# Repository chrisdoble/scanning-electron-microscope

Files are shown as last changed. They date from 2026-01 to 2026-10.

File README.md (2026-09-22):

This repository contains my DIY scanning electron microscope project.

My initial goal is to image samples using secondary electron emission and control the microscope from my computer.

I'm also documenting the process on YouTube [here](https://www.youtube.com/playlist?list=PLmlXFuUXRl5AR0MqcsTuL44zxy5YJyGKN).

# Roadmap

- [x] Purchase vacuum equipment
  - Edwards ADC MkII gauge controller
  - Edwards WRG-S wide range pressure gauge
  - Pfeiffer TC-600 turbomolecular pump controller
  - Pfeiffer TMH 071 P turbomolecular pump
- [x] Build a controller for the vacuum equipment
- [ ] Build a filament characterisation system
- [ ] Build an electron gun
- [ ] Build electrostatic or electromagnetic lenses
- [ ] Build an Everhart-Thornley detector
- [ ] ???
- [ ] Look at stuff

# Repository structure

The repository structure is as follows:

- [`controller`](controller): Contains files relating to the controller hardware that enables communication with the vacuum equipment, controls relays, etc.
- [`common`](common): A Rust crate containing code common to `firmware` and `host`.
- [`electron-gun-simulation`](electron-gun-simulation): A web-based simulation of an electron gun.
- [`filament-characterisation`](filament-characterisation): Contains files relating to the hardware and software used to characterise tungsten filaments to be used in the SEM.
- [`host`](host): A Rust crate containing both a library for interfacing with the controller hardware (pressure gauge, turbo molecular pump, etc.) and a binary for doing the same via a TUI.
- [`usb-tmc`](usb-tmc): A Rust crate containing an implementation of the [USB Test and Measurement Class](https://www.usb.org/document-library/test-measurement-class-specification) for interfacing with oscilloscopes, power supplies, etc.

# Required hardware

- A [Rigol DHO-814 oscilloscope](https://core-electronics.com.au/rigol-dho-814-oscilloscope.html)
- A [Rigol DP-932E power supply](https://core-electronics.com.au/rigol-dp-932e-triple-output-dc-power-supply.html)
- The custom controller as detailed in the [`controller`](controller) directory.
- The vacuum equipment mentioned above

# Running

See each directory's `README.md` for instructions.

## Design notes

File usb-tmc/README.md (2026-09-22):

A small async Rust library for communicating with a single USBTMC (USB Test
and Measurement Class) instrument — e.g. an oscilloscope or power supply —
over its bulk endpoints, built on [`rusb`].

See [`docs/API.md`](docs/API.md) for the full API design.

[`rusb`]: https://docs.rs/rusb

# Requirements

- [Rust](https://rust-lang.org/)
- [libusb](https://libusb.info/), e.g. via `brew install libusb` on macOS

# Features

- Find a device by USB vendor/product ID, open it, and locate its USBTMC
  interface and bulk endpoints.
- Read the interface's capabilities (`GET_CAPABILITIES`) and, if it accepts
  them, assert REN (`REN_CONTROL`), without which a USB488 instrument may
  ignore everything it's sent until something else takes it out of local mode.
- Send a message to the device (`DEV_DEP_MSG_OUT`).
- Request a response and read it back in full
  (`REQUEST_DEV_DEP_MSG_IN`/`DEV_DEP_MSG_IN`), reassembling multi-transfer
  responses using the End-Of-Message (EOM) bit.

# Limitations

- No support for the control-endpoint requests used to abort or recover a
  stuck transfer — if the host and device get out of sync, drop and reopen
  the `UsbTmcDevice`. Note that reopening asserts REN again but doesn't clear
  the device's bulk pipes, which is what `INITIATE_CLEAR` is for.
- REN is asserted on every `open` and never released — there's no
  `GO_TO_LOCAL`, so an instrument stays in remote mode until its Local key is
  pressed or it's power cycled.
- `read` relies solely on the EOM bit; `TermChar`-based early termination
  isn't supported.
- If multiple devices match the given vendor/product ID, `open` returns an
  error rather than picking one.
- Targets macOS — `open` doesn't attempt to detach a kernel driver before
  claiming the interface.

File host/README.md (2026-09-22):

This crate contains both a library for interfacing with the controller hardware (pressure gauge, turbo molecular pump, etc.) and a binary for doing the same via a TUI.

# Requirements

- [libusb](https://libusb.info/), e.g. via `brew install libusb` on macOS
- [Rust](https://rust-lang.org/)

# Running

1. Run `cargo run --bin vacuum -- <device path> <ADC gauge number> <TMP address>`, e.g. `cargo run --bin vacuum -- /dev/tty.usbmodem11201 1 001`.

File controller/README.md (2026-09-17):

This directory contains files relating to the controller hardware that enables communication with the vacuum equipment, controls relays, etc.

# Directory structure

- [`case`](case): 3D models of the controller case for 3D printing.
- [`electronics`](electronics): KiCad files for the controller PCB.
- [`firmware`](firmware): A Rust crate containing the [Embassy](https://github.com/embassy-rs/embassy)-based firmware for the controller.

# Required hardware

- The PCB detailed in the KiCad files including
  - [Raspberry Pi Debug Probe](https://www.raspberrypi.com/documentation/microcontrollers/debug-probe.html)
  - [Raspberry Pi Pico 2](https://www.raspberrypi.com/products/raspberry-pi-pico-2/)
  - [UART-to-RS-232 converter](https://core-electronics.com.au/rs232-to-serial-converter.html)
  - [UART-to-RS-485 converter](https://core-electronics.com.au/ttl-uart-to-rs485-converter-module.html)
  - Various headers and resistors
- 2 x [SPDT relays](https://core-electronics.com.au/gravity-digital-relay-module-arduino-and-raspberry-pi-compatible.html) for reversing filament heating current
- 6 x [Banana sockets](https://www.jaycar.com.au/red-deluxe-binding-post/p/PT0453)

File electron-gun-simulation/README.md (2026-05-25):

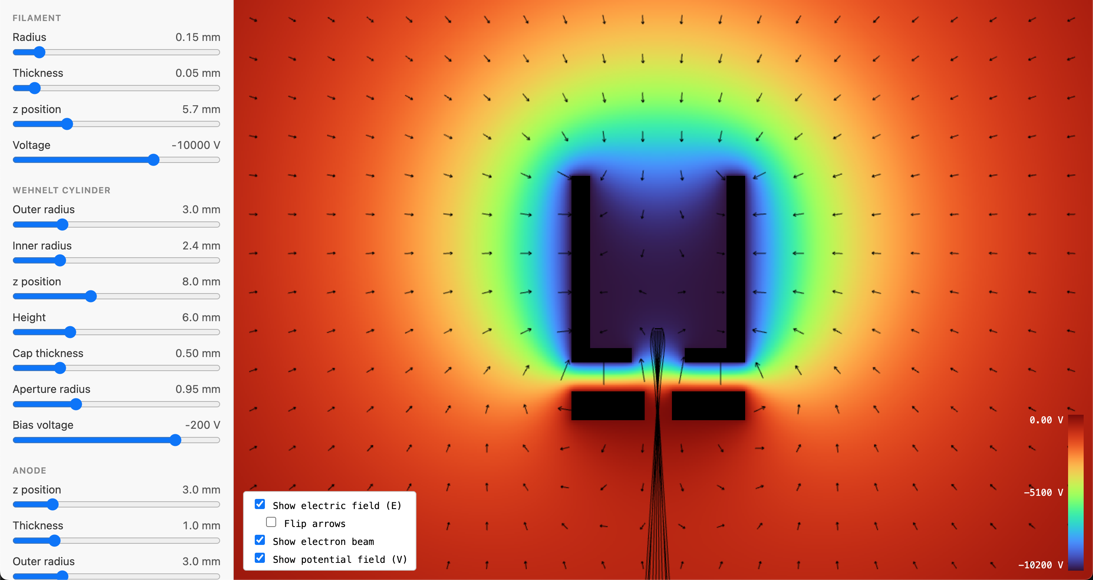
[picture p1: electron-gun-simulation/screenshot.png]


# Requirements

- [pnpm](https://pnpm.io/)
- [Rust](https://rust-lang.org/)
- [wasm-pack](https://wasm-bindgen.github.io/wasm-pack/)

# Running

1. Run

   ```console
   $ (cd crates/wasm-api && wasm-pack build -t web)
   $ cd web
   $ pnpm install
   $ pnpm dev
   ```

1. Open the URL printed in your terminal.

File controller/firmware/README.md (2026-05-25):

# Requirements

- [probe-rs](https://probe.rs/)
- [Rust](https://rust-lang.org/)

# Running

1. Connect the Pi Debug Probe and Pico 2 to your computer.
1. Run `cargo run`. This uploads the firmware to the Pico 2 via the Debug Probe, runs it, and prints subsequent log messages. You don't need to run this again unless you change the firmware or want to see log messages.

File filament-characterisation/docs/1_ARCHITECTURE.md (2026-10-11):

# Filament Characterisation TUI — Specification

A Ratatui application that drives the DIY SEM vacuum rig and steps an operator
through characterising a tungsten filament.

This document specifies **structure only**. The actual characterisation physics
and measurement logic are deliberately stubbed — the deliverable is a skeleton
that compiles, runs against mock hardware, renders the UI, executes a
step-by-step procedure, handles user input, records measurements to a
serialisable struct, shells out to Python for statistics, and cleans up safely
on error.

---

## 1. Goals

1. Reuse the existing `Adc`, `Tmp` and `Controller` types, and the forthcoming
   `PowerSupply` and `Oscilloscope` types, from the `host` crate.
2. Separate concerns into Tokio tasks: hardware polling, procedure execution,
   terminal input, rendering.
3. Model the procedure as a tree of **steps** written as ordinary sequential
   code, rendered as a scrollable, nested list.
4. Support user interaction mid-procedure (confirmations, value entry).
5. Collect measurements — raw samples and the values derived from them — into a
   single in-memory struct written to disk at explicit checkpoints, so a run
   that fails part-way still leaves usable data behind.
6. Run without hardware attached (`--mock`) so the UI can be compiled and
   exercised away from the rig.
7. Delegate statistics and uncertainty propagation to Python scripts shipped
   inside the crate, run through a virtual environment verified at start-up.
8. Guarantee that any error, panic or quit runs a cleanup routine that puts the
   filament system into a safe state.

## 2. Non-goals

- No real characterisation logic. Procedure steps perform sleeps, mock reads
  and placeholder measurements.
- **No emission-current measurement.** That comes in a later version; §17 lists
  the extension points that must stay open for it.
- No charts. Every step renders as text; §9.4 explains what adding a chart later
  would cost.
- No statistics in Rust. The crate records samples and calls Python to turn them
  into a value and an uncertainty.
- No realistic hardware simulation. The mocks return canned values so the UI
  compiles and runs; they are not a model of the rig.
- No fleshing out of the measurement struct. It has almost no fields yet by
  design (§10).

## 3. Assumptions

Implement against these; flag them in the PR description rather than guessing
differently.

| # | Assumption |
|---|---|
| A1 | `filament-characterisation/` is a new **grouping directory**, a sibling of `host/` and `common/` in the existing Cargo workspace. It is not itself a crate. |
| A2 | The new crate lives at `filament-characterisation/characteriser/`, is named `characteriser`, and defines its binary in `src/main.rs`. Add it to the workspace `members`. |
| A3 | The filament power supply, its polarity relays and the four-terminal sense measurement are reached through `host::power_supply::PowerSupply` and `host::oscilloscope::Oscilloscope`. `PowerSupply` holds its own `Arc<Controller>`, through which it switches the SPDT relays. Both instruments are found by hard-coded USB vendor and product IDs — never by command line argument. |
| A4 | The vacuum hardware is reached exactly as the existing binary does: one `Controller` over serial, shared by `Adc` and `Tmp` via `Arc`. The same `Controller` is shared with `PowerSupply`. |
| A5 | Shared dependency versions are hoisted from `host` into `[workspace.dependencies]` and pinned there (§4.1). Take the versions `host` currently declares; do not upgrade anything as part of the move. |
| A6 | Keep `#[tokio::main(flavor = "current_thread")]` as in the existing binary. All blocking serial I/O already happens inside `spawn_blocking` within `Controller`. |
| A7 | `host` depends on `serde` only to derive `Serialize`/`Deserialize` on plain data types that the results store directly, such as `Polarity` (§7.2). This supersedes the original "`host` stays free of `serde`"; see `2_COLD_RESISTANCE.md`. |
| A8 | The Python virtual environment lives at `characteriser/python/.venv` and is created by the operator, not by the application (§12). |
| A9 | Development and operation are on macOS/Linux. Paths like `python/.venv/bin/python` are used directly, without a Windows branch. |

---

## 4. Workspace layout

```
filament-characterisation/
  characteriser/
    Cargo.toml
    python/
      .venv/                        // created by the operator with uv, gitignored
      .python-version               // the Python version the environment uses
      requirements.txt              // pins `jsonschema`, `numpy`, `scipy` and `uncertainties`
      schemas/                      // input and output schemas, generated from the Rust types
      script_io.py                  // reads and validates a script's input, writes its output
      mean_and_standard_error.py    // samples in, value and uncertainty out
      cold_resistance_point.py      // one setpoint's two polarities in, its resistance out
      cold_resistance_fit.py        // every setpoint in, R0 and its uncertainty budget out
      test_cold_resistance.py       // the scripts' tests, run with `python -m unittest`
    src/
      main.rs                 // args, logging, start-up checks, task wiring, error handling
      app.rs                  // App state, event loop, key handling
      hardware/
        mod.rs                // traits, snapshots, the Hardware bundle
        real.rs               // impls over Adc / Tmp / PowerSupply / Oscilloscope
        mock.rs               // canned-value implementations
      procedure/
        mod.rs                // Context and the procedure runner
        characterisation.rs   // the procedure itself
      python.rs               // venv verification and script invocation
      results.rs              // Characterisation, Measurement, serialisation
      steps.rs                // Step, Section, and their rendering
      ui/
        mod.rs                // layout + top-level render
        filament.rs           // filament stats block
        run.rs                // run status block
        steps.rs              // scrollable step list
        vacuum.rs             // vacuum stats block
```

Add `python/.venv/` and `out/` to `.gitignore` if they aren't there already.

### 4.1 Hoisting dependencies to the workspace

Before writing any application code, move the shared dependencies out of
`host/Cargo.toml` (and the existing binary's) into the workspace root:

```toml
# Cargo.toml (workspace root)
[workspace.dependencies]
clap = { version = "<as in host>", features = ["derive"] }
crossterm = "<as in host>"
env_logger = "<as in host>"
log = "<as in host>"
ratatui = "<as in host>"
serde = { version = "<as resolved>", features = ["derive"] }
serialport = "<as in host>"
thiserror = "<as in host>"
tokio = { version = "<as in host>", features = ["macros", "rt", "sync", "time"] }
```

Pin each to the exact version currently resolved in `Cargo.lock` so this move
changes nothing at build time. Then rewrite the member crates to use
`dependency = { workspace = true }`, adding extra features locally where needed.
Verify with `cargo tree` that no version changed, and that `host` and the
existing binary still build, before moving on.

The new crate's manifest:

```toml
[dependencies]
async-trait = "0.1"
clap = { workspace = true }
common = { path = "../../common" }
crossterm = { workspace = true, features = ["event-stream"] }
env_logger = { workspace = true }
futures = "0.3"              # StreamExt, for the crossterm EventStream
host = { path = "../../host" }
log = { workspace = true }
ratatui = { workspace = true }
serde = { workspace = true }
serde_json = "1"
thiserror = { workspace = true }
tokio = { workspace = true, features = ["process"] }
tokio-util = { version = "0.7", features = ["rt"] }   # CancellationToken
```

---

## 5. Command line arguments

Identical to the existing binary, plus `--mock`. Positional arguments become
optional only when `--mock` is given. **No arguments are added for the power
supply, the oscilloscope or the Python environment** — those are located by
hard-coded constants.

```rust
#[derive(Parser)]
struct Arguments {
    /// The path to the controller device, e.g. /dev/tty.usbmodem11201.
    #[arg(required_unless_present = "mock")]
    device_path: Option<String>,

    /// The gauge number to use when communicating with the ADC, e.g. 1.
    #[arg(
        required_unless_present = "mock",
        value_parser = clap::value_parser!(u8).range(1..=2)
    )]
    adc_gauge_number: Option<u8>,

    /// The address of the TMP in the RS-485 Pfeiffer Vacuum Protocol, e.g. 001.
    ///
    /// This corresponds to TMP parameter 797.
    #[arg(required_unless_present = "mock")]
    tmp_address: Option<String>,

    /// Run against simulated hardware instead of the real rig.
    #[arg(long)]
    mock: bool,
}
```

---

## 6. Logging

Copy `init_logging` from the existing binary verbatim, with one fix: create the
output directory first so a fresh checkout doesn't fail.

```rust
/// Initialise `env_logger` to log to `out/app.log`.
fn init_logging() -> Result<(), std::io::Error> {
    fs::create_dir_all("out")?;
    let file = fs::OpenOptions::new()
        .append(true)
        .create(true)
        .open("out/app.log")?;

    Builder::from_default_env()
        .target(Target::Pipe(Box::new(file)))
        .init();

    info!("Application started");
    Ok(())
}
```

Nothing may ever be written to stdout or stderr while the alternate screen is
active. Log levels:

- `info!` — lifecycle: start, section entered, results written, Python script
  invoked, cleanup run, exit. Also a note at start-up saying whether the
  filament system is real or mocked.
- `debug!` — every hardware read/write, and the full command line of every
  Python invocation.
- `warn!` — a hardware read that failed but is being retried.
- `error!` — before returning any `Err`, matching the existing style.

---

## 7. Hardware abstraction

### 7.1 Snapshots

Plain data, taken once per poll. Every field is a real reading: if an instrument
can't be read, that is an error (§8.1), not a missing field.

```rust
/// A snapshot of the vacuum system, taken by the hardware poll task.
///
/// `Copy` because every field is, and snapshots are passed around by value.
/// Drop it if a non-`Copy` field is ever added. Deliberately not `Default`:
/// there is no such thing as a default reading, and the absence of readings is
/// modelled by the absence of a snapshot (§13).
#[derive(Clone, Copy, Debug)]
pub struct VacuumSnapshot {
    /// The chamber pressure.
    pub pressure: Pressure,

    /// The current draw of the TMP in amperes.
    pub tmp_current: f32,

    /// The current rotation speed of the TMP in hertz.
    pub tmp_current_rotation_speed: u16,

    /// If the TMP is running.
    pub tmp_running: bool,

    /// The target rotation speed of the TMP in hertz.
    pub tmp_target_rotation_speed: u16,
}

/// A snapshot of the filament system, taken by the hardware poll task.
#[derive(Clone, Copy, Debug)]
pub struct FilamentSnapshot {
    /// The voltage across the filament in volts, from four-terminal sensing.
    pub filament_voltage: f64,

    /// The current flowing through the filament in amperes.
    pub heating_current: f64,

    /// If the power supply output is enabled.
    pub output_enabled: bool,

    /// How the filament is connected to the supply.
    pub polarity: Polarity,
}

/// Both snapshots, published together so the UI and the procedure always see a
/// consistent pair.
#[derive(Clone, Copy, Debug)]
pub struct Snapshots {
    pub filament: FilamentSnapshot,
    pub vacuum: VacuumSnapshot,
}
```

No derived quantities live on the snapshots. Resistance is calculated from
recorded measurements by the Python side, with uncertainties, and the TUI never
computes its own version.

### 7.2 Polarity

The filament sits between two SPDT relays, each of which connects its side of
the filament to either rail of the supply. Four relay states exist; three
distinct connections matter, and only these are exposed:

```rust
/// The direction of the current through the filament.
///
/// Each side of the filament is switched by one SPDT relay. With both relays
/// de-energised, both sides sit on the negative rail, no current can flow, and
/// the current has no direction — that's `Nil`. That is the state the
/// controller powers up in, and the state cleanup returns to. Energising one
/// relay or the other puts one side on the positive rail, setting the
/// direction.
///
/// Reversing the direction lets the Seebeck voltages at the filament's
/// junctions cancel when a forward and a reverse measurement are averaged.
///
/// A fourth relay state exists — both energised, both sides on the positive
/// rail — which is equivalent to `Nil` and is never used.
#[derive(Clone, Copy, Debug, Default, Deserialize, Eq, PartialEq, Serialize)]
pub enum Polarity {
    /// Relay 1 energised: current flows through the filament one way.
    Forward,

    /// Both relays de-energised: no current flows, so there is no polarity.
    #[default]
    Nil,

    /// Relay 2 energised: current flows the other way.
    Reverse,
}
```

This enum belongs in `host` beside `PowerSupply` (§7.5), since the supply is
what switches the relays. It derives `Serialize` and `Deserialize` so
`results.rs` can store it directly (A7).

### 7.3 Traits

One trait per subsystem. Both are `dyn`-compatible via `#[async_trait]`, and
both are `Send + Sync + Debug` so they can live in an `Arc` shared between the
poll task and the procedure task. Reads are named `get_*` to match `Tmp` and
`Adc` in `host`.

```rust
/// A vacuum system: a pressure gauge and a turbomolecular pump.
#[async_trait]
pub trait VacuumSystem: std::fmt::Debug + Send + Sync {
    /// Reads every value shown in the vacuum block in a single pass.
    async fn snapshot(&self) -> Result<VacuumSnapshot, HardwareError>;

    /// Turns the TMP on or off.
    ///
    /// IMPORTANT: Callers must confirm the chamber pressure is below
    /// `TMP_MAXIMUM_BACKING_PRESSURE_MBAR` and that the roughing pump is
    /// running before turning the TMP on, otherwise it may be damaged.
    async fn set_tmp_running(&self, running: bool) -> Result<(), HardwareError>;
}

/// The filament system: the power supply, its polarity relays, and the
/// oscilloscope measuring the voltage across the filament.
#[async_trait]
pub trait FilamentSystem: std::fmt::Debug + Send + Sync {
    /// Reads every value shown in the filament block in a single pass.
    async fn snapshot(&self) -> Result<FilamentSnapshot, HardwareError>;

    /// Measures the voltage across the filament in volts.
    ///
    /// This is the sense pair of the four-terminal measurement, so it excludes
    /// the drop across the supply leads and the feedthroughs.
    async fn get_filament_voltage(&self) -> Result<f64, HardwareError>;

    /// Measures the current through the filament in amperes.
    async fn get_heating_current(&self) -> Result<f64, HardwareError>;

    /// Sets the channel's current limit in amperes.
    ///
    /// Must be rejected above `MAXIMUM_HEATING_CURRENT_AMPS`.
    async fn set_heating_current_limit(&self, current: f64) -> Result<(), HardwareError>;

    /// Sets the channel's voltage limit in volts.
    ///
    /// The supply runs in whichever mode its limits make it: with the voltage
    /// limit set high, the current limit is what binds and the channel runs in
    /// constant current. Called once at the start of a run with a large value
    /// so every later `set_heating_current_limit` is the limiting factor.
    async fn set_heating_voltage_limit(&self, voltage: f64) -> Result<(), HardwareError>;

    /// Enables or disables the output.
    async fn set_output_enabled(&self, enabled: bool) -> Result<(), HardwareError>;

    /// Sets the direction of the current through the filament via the relays.
    ///
    /// IMPORTANT: The output must be disabled before the relays are switched,
    /// otherwise the contacts will arc. Implementations must enforce this
    /// rather than trusting the caller.
    async fn set_polarity(&self, polarity: Polarity) -> Result<(), HardwareError>;

    /// Puts the filament system into a safe state.
    ///
    /// Called on every exit path: normal completion, procedure error, user
    /// quit, and panic. Must be idempotent and must not return early on the
    /// first failure — every action is attempted and failures are logged.
    ///
    /// In order: zero the current, disable the output, then
    /// `set_polarity(Polarity::Nil)` to de-energise both relays.
    async fn enter_safe_state(&self);
}
```

`get_filament_voltage` and `get_heating_current` exist separately from
`snapshot` because a measurement takes `SAMPLE_COUNT` samples in quick
succession (§10.1), far faster than the one-per-second the snapshot provides.
`VacuumSystem` needs no such method: nothing wants a one-off vacuum reading,
because the procedure waits on the snapshot stream instead (§11.1).

### 7.4 The `Hardware` bundle

```rust
/// Everything the application can talk to.
///
/// Field-only: with `snapshot` and `enter_safe_state` on the traits themselves,
/// this exists solely so functions take one parameter instead of two.
#[derive(Clone, Debug)]
pub struct Hardware {
    pub filament: Arc<dyn FilamentSystem>,
    pub vacuum: Arc<dyn VacuumSystem>,
}
```

Two separate `Arc`s rather than one combined trait means the real vacuum system
can be paired with a mock filament system — which is where development starts,
since the `host` types may not exist yet. `--mock` is a single flag; partial
mocking is a constructor choice inside `build_hardware`.

### 7.5 Real implementations

`real.rs` holds thin adapters:

- `RealVacuumSystem { adc: Adc, tmp: Tmp }`, constructed from an
  `Arc<Controller>` exactly as the existing binary does, including the
  `set_pressure_unit(PressureUnit::Millibar)` call at start-up.
- `RealFilamentSystem { oscilloscope: Oscilloscope, power_supply: PowerSupply }`.

Each adapter only maps types and errors; no logic lives here. The channel
constants live here too:

```rust
/// The oscilloscope channel probing the filament's sense pair.
const SENSE_CHANNEL: u8 = 1;

/// The power supply channel driving the filament.
const SUPPLY_CHANNEL: u8 = 1;
```

**Before writing these, check what `host` actually exposes.** If
`host::power_supply::PowerSupply` and `host::oscilloscope::Oscilloscope` don't
exist yet, add them to `host` as minimal modules following the exact shape of
`adc.rs` and `tmp.rs` — a `thiserror` error enum wrapping `ControllerError`, a
struct holding its state behind a `tokio::sync::Mutex`, async methods, doc
comments with units — with method bodies returning a `NotImplemented` variant
and a `TODO` naming the instrument and protocol still to be wired up. Both are
found by USB vendor and product ID, declared as constants in their own module
with a comment naming the instrument they identify:

```rust
impl PowerSupply {
    /// `controller` is used to switch the SPDT polarity relays.
    ///
    /// The supply itself is found by its USB vendor and product IDs.
    pub fn new(controller: Arc<Controller>, channel: u8) -> Result<Self, PowerSupplyError>;

    pub async fn get_current(&self) -> Result<f64, PowerSupplyError>;
    pub async fn get_output_enabled(&self) -> Result<bool, PowerSupplyError>;
    pub async fn get_polarity(&self) -> Result<Polarity, PowerSupplyError>;
    pub async fn set_current(&self, current: f64) -> Result<(), PowerSupplyError>;
    pub async fn set_output_enabled(&self, enabled: bool) -> Result<(), PowerSupplyError>;
    pub async fn set_polarity(&self, polarity: Polarity) -> Result<(), PowerSupplyError>;
    pub async fn set_voltage(&self, voltage: f64) -> Result<(), PowerSupplyError>;
}

impl Oscilloscope {
    /// Found by its USB vendor and product IDs.
    pub fn new() -> Result<Self, OscilloscopeError>;

    /// Measures the mean voltage on `channel` in volts.
    pub async fn measure_voltage(&self, channel: u8) -> Result<f64, OscilloscopeError>;
}
```

If the real signatures differ, `real.rs` is the only file that changes. Keep it
that way — nothing outside `hardware/real.rs` may name a `host` instrument type.
Plain data types from `host`, such as `Polarity` and `host::oscilloscope::Voltages`,
are an exception: they're values, not instruments, so the traits use them
directly.

While the supply and oscilloscope are stubbed, `build_hardware` substitutes the
mock filament system even without `--mock` and logs that it has done so.

### 7.6 Mock implementations

The mocks exist so the application compiles and the UI can be exercised. They
are **not** a simulation. Each getter returns a canned constant and each setter
stores the value it was given, so the snapshot reflects what was set. Constants
at the top of the file, one line each. No time dependence, no noise, no physics.

Two behaviours are kept because they're contracts rather than simulation:
`set_heating_current_limit` above `MAXIMUM_HEATING_CURRENT_AMPS` errors, and
`set_polarity` errors while the output is enabled.

### 7.7 Errors

```rust
#[derive(Debug, Error)]
pub enum HardwareError {
    #[error("adc error: {0}")]
    Adc(#[from] AdcError),
    #[error("oscilloscope error: {0}")]
    Oscilloscope(#[from] OscilloscopeError),
    #[error("power supply error: {0}")]
    PowerSupply(#[from] PowerSupplyError),
    #[error("tmp error: {0}")]
    Tmp(#[from] TmpError),
    #[error("not implemented")]
    NotImplemented,
    #[error("{0}")]
    Other(String),
}
```

---

## 8. Application architecture

### 8.1 Tasks and shared state

```
        ┌──────────────────┐
        │  hardware poll   │  every POLL_INTERVAL (1 s)
        │      task        │  vacuum.snapshot() + filament.snapshot()
        └────────┬─────────┘
                 │ watch::Sender<Option<Snapshots>>
        ┌────────┴──────────────────────┐
        ▼                               ▼
┌──────────────────┐            ┌───────────────┐
│  app event loop  │            │ procedure     │
│  (main task)     │            │ task          │
│  owns terminal   │            │ Context       │
└────────┬─────────┘            └───────┬───────┘
         │  reads            mutates    │
         └───────► Arc<Mutex<Section>> ◄┘
         ▲
         │ mpsc::Receiver<AppEvent>  (HardwareFailed, ProcedureFinished)
         │ crossterm EventStream
```

- **App event loop (main task).** Owns the `DefaultTerminal` — never shared, so
  only this task draws. Selects over the `AppEvent` receiver, the crossterm
  `EventStream`, the snapshot watch, and a render tick.
- **Hardware poll task.** Sleeps `POLL_INTERVAL` (1 s, a `const` with a doc
  comment), takes both snapshots, publishes `Snapshots` on the watch channel.
  A failed read is retried on the next tick with a `warn!`. After
  `POLL_FAILURE_TOLERANCE` consecutive failures (3) it sends
  `AppEvent::HardwareFailed`, which is fatal: the app shuts down and cleanup
  runs. A serial timeout mid-run shouldn't end a forty-minute pump-down, but
  persistent failure means the rig is no longer under control and the filament
  shouldn't stay powered. Both constants get doc comments saying this.
- **Procedure task.** Runs the procedure against a `Context`. Started **after
  the first snapshot arrives** (§13), so nothing runs against instruments that
  haven't answered yet. Sends `AppEvent::ProcedureFinished(result)` when done.
- **No separate render task.** Rendering happens in the app loop, because the
  terminal would otherwise have to be shared. Say so in a comment.

**What `main` creates and hands out.** Before spawning anything:

- `let cancel = CancellationToken::new();` — cloned into the `Context` and kept
  by `main`, which calls `cancel.cancel()` as the first step of shutdown (§16),
  once the event loop has returned. It is the only cancellation channel; nothing
  else signals the procedure to stop. The poll task isn't given it: it only
  reads, so it's left running through shutdown and ends when `main` returns.
- `let root = Arc::new(Mutex::new(Section::default()));` — the step tree, cloned
  into the `Context` and kept by `App`.
- `let characterisation = Characterisation::new();` and
  `let results_path = characterisation.path();` — the run's measurements, moved
  into the `Context`, and where they're written, kept by `main` so it can be
  printed on exit. The `Context` doesn't need the path: `save` knows it.
- `let (snapshots_tx, snapshots_rx) = watch::channel(None);` — the sender goes to
  the poll task, receivers to `App` and to the `Context`.
- `let (events_tx, events_rx) = mpsc::channel(EVENT_CHANNEL_CAPACITY);` — the
  sender is cloned into the poll task and the procedure task.

Render tick: `RENDER_INTERVAL = 50 ms` (20 fps), enough for spinner animation.

### 8.2 Events

The message channel carries only what can't be expressed as shared state:

```rust
/// An out-of-band message to the application's event loop.
#[derive(Debug)]
pub enum AppEvent {
    /// The hardware has failed persistently and the run can't continue.
    HardwareFailed(HardwareError),

    /// The procedure task has finished, successfully or otherwise.
    ProcedureFinished(Result<(), ProcedureError>),
}
```

Steps are shared state (§9) and snapshots are a watch channel, so neither
appears here.

### 8.3 How `select!` behaves, and why this is safe

`tokio::select!` polls every branch's future concurrently and, when one
completes, drops the others. Dropping a future cancels whatever work it was
doing — so the question isn't whether the other branches get cancelled (they do)
but whether cancelling them **loses anything**. A future is *cancellation-safe*
if dropping it mid-poll leaves no state behind.

All four branches here are cancellation-safe, because their state lives in a
long-lived object outside the future:

- `mpsc::Receiver::recv()` — an unreceived message stays in the channel.
- `futures::StreamExt::next()` on `EventStream` — an unread key event stays in
  the stream's buffer.
- `watch::Receiver::changed()` — the value stays in the channel, and the
  receiver's "seen" marker only advances when `changed()` actually resolves.
- `tokio::time::Interval::tick()` — the deadline lives in the `Interval`.

Each loop iteration creates fresh futures from those long-lived objects, so a
branch that lost the race is simply re-awaited next iteration with nothing
missed:

```rust
loop {
    tokio::select! {
        Some(event) = events.recv() => self.handle_app_event(event),
        Some(Ok(event)) = terminal_events.next() => self.handle_terminal_event(event),
        Ok(()) = snapshots.changed() => self.handle_snapshot(*snapshots.borrow_and_update()),
        _ = ticker.tick() => self.render(&mut terminal)?,
    }
}
```

Put a comment above the loop saying exactly this, and one rule beside it: **only
cancellation-safe futures go directly in a `select!` branch.** Anything that
buffers into a local (a multi-step read, a partially consumed iterator) must be
driven by a task and its result delivered over a channel instead.

### 8.4 Terminal input

Use `crossterm::event::EventStream` so input can be selected alongside
everything else, rather than the blocking `poll`/`read` pair the existing binary
uses. This needs `features = ["event-stream"]` on `crossterm`, which the
workspace pin (§4.1) keeps in step with ratatui's copy.

---

## 9. The step tree

The tree lives in `Arc<Mutex<Section>>` — one root section — shared between the
procedure task (which mutates) and the app loop (which renders). Direct mutation
replaces passing step changes as messages, which would mean enumerating every
kind of mutation as an event variant and naming the node each one applies to.

There is no wrapper type around it and no revision counter. The app redraws on
every tick unconditionally: the running step animates a spinner, so most frames
would redraw anyway, and ratatui diffs the previous and current buffers and
writes only the cells that changed — so a redraw of unchanged content costs a
little line-building and no terminal I/O. A revision counter would save that
line-building only while the procedure is blocked on a prompt. Not worth the
second source of truth.

### 9.1 Types

A step is a struct carrying what every step has, plus an enum for what differs.
Children belong only to sections, so they live in the `Section` struct rather
than on every step.

```rust
/// A single step in the procedure.
#[derive(Debug)]
pub struct Step {
    /// When the step finished, if it has.
    pub finished_at: Option<Instant>,

    pub kind: StepKind,

    pub started_at: Instant,

    pub status: StepStatus,
}

/// What a step displays and how the user interacts with it.
#[derive(Debug)]
pub enum StepKind {
    /// A gate: something the user has to make true, e.g. "Confirm that the
    /// roughing pump is running", before the procedure continues.
    ///
    /// Not a yes/no question, which is `Question`. There's no answer to record —
    /// the step's status and `finished_at` say that it was passed and when — and
    /// no way to refuse: a user who can't make it true quits instead.
    Confirm {
        prompt: String,

        /// Taken by the application when the user confirms.
        ///
        /// `Some` exactly while this step is waiting for input, which is what
        /// `Section::pending_mut` looks for.
        responder: Option<oneshot::Sender<()>>,
    },

    /// A value typed by the user.
    Input {
        /// What the user has typed so far.
        buffer: String,

        /// Set when the buffer failed to parse, and shown beside the prompt.
        error: Option<String>,

        prompt: String,

        /// Taken by the application when the user submits a value.
        responder: Option<oneshot::Sender<String>>,

        /// The unit shown after the input field, e.g. "A".
        unit: Option<String>,

        /// The accepted value, set by the procedure once parsed.
        value: Option<String>,
    },

    /// A yes/no question, e.g. "Turn off the TMP and wait for it to spin
    /// down?".
    ///
    /// Unlike `Confirm`, "no" is a real answer, and it's recorded.
    Question {
        /// The answer, once given: `true` for yes.
        answer: Option<bool>,

        prompt: String,

        /// Taken by the application when the user answers.
        responder: Option<oneshot::Sender<bool>>,
    },

    /// A group of steps.
    Section(Section),

    /// One line of styled text: a remark, a measurement, an error, or something
    /// still in progress.
    ///
    /// These differ only in their spans and their status, so they are one kind
    /// with three constructors. A step that is still `Running` renders with a
    /// spinner and a live elapsed time, which is what makes it a "waiting"
    /// step; it stops the moment the procedure finishes it.
    ///
    /// `Vec<Span>` rather than a `Line` because the renderer prepends the
    /// indentation and status glyph and assembles the `Line` itself; a `Line`
    /// would carry its own alignment and style that the assembly would have to
    /// reconcile.
    Text { spans: Vec<Span<'static>> },
}

/// A group of steps with a title.
///
/// `Default` gives the root of the tree: no children and no title, because the
/// UI renders the root's children rather than the root itself.
#[derive(Debug, Default)]
pub struct Section {
    /// The steps nested beneath this one, in the order they began.
    pub children: Vec<Step>,

    pub title: String,
}

#[derive(Clone, Copy, Debug, Default, Eq, PartialEq)]
pub enum StepStatus {
    Done,
    Failed,
    #[default]
    Running,
}
```

All styling lives in constructors, so no caller assembles spans by hand and the
renderer never needs to know why a line looks the way it does:

```rust
impl StepKind {
    /// A fatal error, styled with `ERROR_STYLE`.
    ///
    /// The step's `status` carries the failure; this is only its appearance.
    pub fn error(message: impl Into<String>) -> Self;

    /// A labelled value, e.g. "Forward voltage: 9.61 ± 0.03 mV".
    ///
    /// The label is rendered in the default style and the value in
    /// `VARIABLE_STYLE`, the two-tone idiom the existing binary uses for every
    /// reading. It's what the operator's eye scans for, and where the `±`
    /// uncertainty goes.
    pub fn measurement(label: impl Into<String>, value: impl Display) -> Self;

    /// A plain line of text.
    pub fn text(text: impl Into<String>) -> Self;
}
```

`Section` is a struct rather than an inline variant body so that `push` and the
lookups below can hang off it.

One import note: don't `use ratatui::text::Text` in `steps.rs`, or it will
collide with `StepKind::Text`. Only `Line` and `Span` are needed.

### 9.2 Addressing a step

```rust
/// The position of a step in the tree, as child indices from the root.
///
/// Paths stay valid for the life of the run because steps are only ever
/// appended — never removed, never reordered.
pub type StepPath = Vec<usize>;

impl Section {
    /// Appends a step and returns its index in `children`.
    pub fn push(&mut self, kind: StepKind) -> usize;

    /// The section at `path`, if it exists and is a section.
    pub fn section_at_mut(&mut self, path: &[usize]) -> Option<&mut Section>;

    /// The step at `path`, if it exists.
    pub fn step_at_mut(&mut self, path: &[usize]) -> Option<&mut Step>;

    /// The step waiting on the user, if any.
    ///
    /// The procedure is sequential, so the step awaiting input can only be the
    /// last one in the tree: follow the last child down through nested sections
    /// and check whether what you land on still holds a responder. That's a
    /// walk of the tree's depth, not its size.
    ///
    /// IMPORTANT: if the procedure ever runs two sections concurrently, this
    /// assumption breaks and this has to become a depth-first search for a step
    /// holding a responder.
    pub fn pending_mut(&mut self) -> Option<&mut Step>;
}
```

The root is `Section::default()`, constructed once in `main` (§8.1).

**Why paths survive even though `push` is a `Section` method.** `Context` is
cloned into every nested section and lives across `await` points, so it can't
hold a `&mut Section` — that's a borrow of data inside a `Mutex` that has to be
released before every await. It has to hold something that can re-find the
section after re-locking, and a path is the smallest such thing. `push` then
lands on `Section` exactly as you'd want: the caller does
`root.section_at_mut(&self.parent)?.push(kind)`, so it's impossible to push a
child onto a `Text` step.

Two alternatives, for the record, both rejected:

- **Give each section its own `Arc<Mutex<Vec<Step>>>`** and have `Context` hold
  that handle directly. This does remove paths, but it replaces one lock with
  one per section, makes `Step` no longer plain data, and turns rendering and
  the pending search into recursive locking. Not worth it.
- **Store only the depth** and walk the rightmost spine, which is always the
  open section while the procedure is strictly sequential. Correct today, and
  silently wrong the first time anyone runs two sections concurrently.

### 9.3 How a confirmation works

A confirmation is a gate, not a question: the procedure states something the
operator has to make true — "Confirm that the roughing pump is running" — and
waits until they press `Enter`. There's no "no". An operator who can't make it
true quits, which cancels the token and unblocks the wait with
`ProcedureError::Cancelled`, and cleanup runs as on any other exit (§16).

A real yes/no choice is a `StepKind::Question`, asked with `Context::ask`, which
returns the answer as a `bool`. It works exactly as below, except that the
responder carries a `bool` rather than `()`, and the procedure records the
answer in the step before finishing it, so the step shows it. `y` answers yes
and `n` answers no (§15).

The responder lives in the step, so no separate request message or pending
registry is needed. The procedure creates the channel, parks the sender in the
tree, and awaits the receiver:

```rust
pub async fn confirm(&self, prompt: impl Into<String>) -> Result<(), ProcedureError> {
    let (responder, confirmation) = oneshot::channel();
    let path = self.push(StepKind::Confirm {
        prompt: prompt.into(),
        responder: Some(responder),
    });

    // The lock is dropped by `push` before we await: the application needs it
    // to render the prompt and to confirm it.
    tokio::select! {
        confirmation = confirmation => confirmation.map_err(|_| ProcedureError::Cancelled)?,
        _ = self.cancel.cancelled() => return Err(ProcedureError::Cancelled),
    };

    self.finish(&path, StepStatus::Done);
    Ok(())
}
```

`push` and `finish` are two of the private `Context` helpers every one of its
methods is built from; they're defined in §11.1.

The application, on `Enter`:

```rust
let mut root = self.root.lock()?;
if let Some(Step { kind: StepKind::Confirm { responder, .. }, .. }) = root.pending_mut() {
    if let Some(responder) = responder.take() {
        // An error here only means the procedure has gone away.
        let _ = responder.send(());
    }
}
```

Three things follow from this arrangement, all worth comments in the code:

- **Taking the responder is what ends the pending state; sending on it is
  what ends the procedure's wait.** Once taken, `pending_mut` stops returning
  the step, so a second `Enter` can't confirm twice. The send wakes the
  procedure — as would dropping the responder unsent, which the receiver sees as
  an error and the procedure treats as cancellation.
- **The procedure owns status.** The app only sends the confirmation; the
  procedure sets `status` and `finished_at` when it wakes. One writer of
  lifecycle state, and it's the one that knows what happens next.
- **Cancellation is the token, not the drop.** The tree is `Arc`-shared and
  outlives the app, so dropping `App` doesn't drop the responder. The `select!`
  on `cancel.cancelled()` is what unblocks a pending prompt at shutdown.

`Context::input` works identically, except the app sends the buffer contents and
the procedure parses them: on failure it writes `error` back into the step,
installs a fresh responder, and awaits again, so the user is re-prompted in
place — and the step stays the last one in the tree, which is what keeps
`pending_mut` correct.

### 9.4 Rendering and scrolling

Every step renders as text, so the tree becomes a list of lines, built by a
method on `Step` that sections call recursively on their children:

```rust
impl Step {
    /// The step as rendered lines.
    ///
    /// Text is never wrapped: a step produces a fixed number of lines — one for
    /// itself, plus whatever its children produce — and anything too wide is
    /// ellipsified to fit. That's what makes scrolling a slice index: the line
    /// count doesn't depend on the width.
    ///
    /// `width` is needed anyway, because a line with a right-hand element — a
    /// section's total elapsed time, a running step's elapsed seconds — lays it
    /// out against the right edge and ellipsifies the left part to fit, so the
    /// time stays visible however long the title is.
    ///
    /// A section renders its title and then calls this on each of its children
    /// with a width `INDENT` columns narrower, indenting what comes back — so
    /// the recursion carries the nesting and no depth parameter is needed.
    ///
    /// Note: this deliberately is not `Widget::render`. Do not implement
    /// `Widget` for `Step` — it would have to draw into a `Rect`, and then
    /// scrolling would need the buffer machinery described below.
    pub fn render(&self, width: u16) -> Vec<Line<'static>>;
}

impl Section {
    /// The section's children as rendered lines.
    ///
    /// Used by `Step::render` for nested sections, and by the UI for the root,
    /// whose own title is never shown.
    pub fn render_children(&self, width: u16) -> Vec<Line<'static>>;
}
```

**Laying out a line.** Each line is assembled left to right: the status glyph,
then the step's own spans, then — if the step has one — a right-hand element
padded flush to `width`. Every line is fitted with a shared helper:

```rust
/// Truncates `spans` to `width` columns, ending the last surviving span with
/// `…` when anything was cut.
fn ellipsify(spans: Vec<Span<'static>>, width: u16) -> Vec<Span<'static>>;
```

A section title is ellipsified to `width - glyph - gap - elapsed`, a running
step's text to the same less its elapsed seconds, and a step with nothing to its
right to `width - glyph`. Everything is ellipsified rather than left to clip at
the block edge, so a truncated line always says so — silent truncation looks
like a short line, and a step list is exactly where a reader would fail to
notice.

**How a section indents its children.** Each line comes back as a
`Line<'static>`, which is a `Vec<Span<'static>>`. Indenting is prepending one
span of spaces:

```rust
/// The columns each level of nesting indents by.
const INDENT: u16 = 2;

fn indent(line: Line<'static>) -> Line<'static> {
    let mut spans = Vec::with_capacity(line.spans.len() + 1);
    spans.push(Span::raw(" ".repeat(INDENT as usize)));
    spans.extend(line.spans);
    Line::from(spans)
}
```

So `Section::render_children` is
`self.children.iter().flat_map(|c| c.render(width.saturating_sub(INDENT))).map(indent)`.
Narrowing the width before rendering and indenting after means a nested
section's right-aligned elapsed time still lands in the correct column once the
indent is prepended.

Two rules make this work, both worth comments: **style at the span level, never
the line level**, so prepending a span can't interact with a line-level style;
and **never set `Line::alignment`** — a section pads to `width` with spaces to
right-align its elapsed time, because ratatui's alignment would be computed
against the drawing area rather than the indented width.

Drawing is then:

```rust
let lines = root.render_children(inner.width);
let visible = &lines[state.offset..(state.offset + inner.height as usize).min(lines.len())];
Paragraph::new(visible.to_vec()).render(inner, buf);
```

No `Wrap` on the `Paragraph`: the lines are already fitted to the width, and
without `Wrap` ratatui truncates rather than reflows anything that still
overruns — a backstop, not the mechanism.

Rendering rules:

- Status glyph prefix: `⟳` running (spinner frames `⠋⠙⠹⠸⠼⠴⠦⠧⠇⠏`, indexed from
  the step's own elapsed time so no tick counter has to be passed in), `✔` done,
  `✖` failed.
- Sections render their title bold, with elapsed time right-aligned.
- A `Running` text step renders its elapsed seconds at the right edge.
- The pending step is highlighted (yellow, as `CONFIRMATION_STYLE` in the
  existing binary) and shows its own hint: `[Enter] Confirm`, or the text buffer
  with a block cursor.

**Why not render the tree recursively into an oversized buffer.** That approach
works, and it's what `tui-scrollview` does: allocate a `Buffer` the full height
of the content, render widgets into it at their own offsets, then copy the
visible window into the frame's buffer. It's the right answer when the content
contains widgets that *can't* be expressed as lines — a `Chart`, a `Gauge`, a
`Sparkline` — because those insist on drawing into a `Rect`. With every step
being one line of text it buys nothing and costs a measure pass, a buffer
allocation per frame, and a second place for the line count to disagree with
the render.

If a chart step is ever added, switch to the buffer approach for the whole list
rather than special-casing one kind — and look at `tui-scrollview` before
writing it by hand. Leave a comment on `Step::render` saying so.

**What ratatui already provides, and what's ours.** Worth knowing so nobody
reimplements the wrong half:

| Ratatui offers | What it does | Why it isn't the whole answer |
|---|---|---|
| `Paragraph::scroll((y, x))` | Skips `y` rendered lines | Stateless: no clamping, no follow behaviour. Equivalent to the slice above, but it re-renders every line each frame. |
| `List` + `ListState` | Keeps an `offset`, tracks a selection, scrolls to keep it visible | The closest fit, and viable now that lines are clipped rather than wrapped — one line per `ListItem`. Its selection semantics still aren't ours (the pending step isn't a cursor the user moves), and driving `offset` directly is about as much code as the slice. Use it if it reads better; nothing else depends on the choice. |
| `Scrollbar` + `ScrollbarState` | Draws a scrollbar | Display only; no scrolling logic. Not used — no scrollbar. |
| `tui-scrollview` (third-party) | The oversized-buffer pattern above | Only needed for non-text content. |

What's genuinely ours is follow-the-tail and keeping the pending step visible —
maybe twenty lines, and neither has a primitive in the library.

### 9.5 Locking rules

- `std::sync::Mutex`, not `tokio::sync::Mutex`. Every critical section is a
  short synchronous mutation or one render pass.
- **The lock is never held across an `.await`.** Put this in a comment where the
  root is declared. `Context` methods take the lock, mutate, and drop it before
  awaiting.
- The app takes the lock once per frame, for the duration of the draw.
- A poisoned lock is fatal: log with `error!` and shut down, matching how
  `Controller` handles its own poisoned mutex.

---

## 10. Measurement data and persistence

### 10.1 The measurement type

Every quantity is measured the same way: take `SAMPLE_COUNT` samples (n = 20),
then ask Python for their mean and standard error. Both halves are kept — the
samples so the analysis can be redone or scrutinised later, the derived pair so
consumers don't have to recompute it.

```rust
/// A measured quantity: the samples taken, and the value derived from them.
///
/// `value` and `uncertainty` are the mean and standard error returned by
/// `mean_and_standard_error.py` (§12), not calculated in Rust.
#[derive(Debug, Deserialize, Serialize)]
pub struct Measurement {
    /// The individual samples, in the order they were taken.
    pub samples: Vec<f64>,

    /// The standard error of the mean.
    pub uncertainty: f64,

    /// The mean of the samples.
    pub value: f64,
}
```

Not implemented yet, but this is the shape every measured field takes, and the
unit goes in the name of the field holding it — `filament_voltage_volts:
Measurement` — since the consumer is another program with no doc comments to
read.

### 10.2 The results struct

```rust
/// Everything measured during one characterisation run.
///
/// Written to disk at checkpoints throughout the procedure so that a run which
/// fails part-way still leaves its partial results behind.
#[derive(Debug, Deserialize, Serialize)]
pub struct Characterisation {
    /// The current through the filament while measuring its cold resistance
    /// in `Polarity::Forward`.
    pub cold_forward_current_amps: Option<Measurement>,

    /// The voltage across the filament while measuring its cold resistance in
    /// `Polarity::Forward`.
    pub cold_forward_voltage_volts: Option<Measurement>,

    /// As above, in `Polarity::Reverse`.
    pub cold_reverse_current_amps: Option<Measurement>,

    /// As above, in `Polarity::Reverse`.
    pub cold_reverse_voltage_volts: Option<Measurement>,

    /// An identifier for the filament under test, entered by the operator.
    pub filament_id: Option<String>,

    /// When the run started, in seconds since the Unix epoch.
    pub started_at: u64,
}

impl Characterisation {
    /// Creates the results for a run starting now.
    pub fn new() -> Self;

    /// Where the results are written, named for `started_at`.
    pub fn path(&self) -> PathBuf;

    /// Writes the results to `path()`.
    ///
    /// Writes to a temporary file and renames it, so killing the program can't
    /// leave a half-written file behind.
    pub fn save(&self) -> Result<(), ResultsError>;
}
```

Every measured field is an `Option` for the same reason `filament_id` is: the
file is saved before anything is measured, and a run quit part-way leaves the
rest as `null`. More fields join these as the real procedure measures more, each
a `Measurement` (or a `Vec` of them for a sweep) named with its unit.

`filament_id` is `None` until the operator enters it. It's the first thing the
procedure asks for, before any measurement is taken, so no results file that
contains a measurement can lack it. But results are saved on every exit path
(§10.3), so a run quit at that first prompt still writes a file — and `None`,
serialised as `null`, says the identifier was never given where an empty string
would look like one that was.

- File name: `out/characterisation-<started_at>.json`, so successive runs don't
  overwrite each other. `Characterisation::path` builds it from `started_at`
  rather than reading the clock again, so the name always matches the time
  recorded inside.
- Format: `serde_json::to_string_pretty`. Confine the format choice to `save`.
- Write to `<path>_new` and `fs::rename` over the real path, the same idiom the
  existing binary uses in `log_pressure` and `graph_pressure`.
- `fs` calls are inline rather than in `spawn_blocking`: the file is small and
  this matches the existing binary. Note it in a comment.

There is no `Results` wrapper type. The struct owns its own `save`, and the
sharing is folded into `Context` (§11.1) — which has to be shared anyway, since
`Context` is cloned into every nested section.

### 10.3 When to save

Saving is **explicit**: the procedure calls `ctx.save()` after each measurement
completes, and the runner saves once more after the procedure returns, on both
the success and error paths, so the final state always reaches disk. The first
save adds a text step reading "Saved results to …"; later saves are logged with
`info!`.

A failed save never aborts the procedure. Log it with `error!`, push a step
marked `Failed`, and carry on — losing the record is worse than losing the rest
of the run.

---

## 11. The procedure

### 11.1 Context

The handle the procedure uses to emit steps, collect user input, read the
hardware and record measurements. Cheap to clone; a clone with a different
`parent` path is what nesting is built from. Every field is handed to it when
the procedure task is spawned (§8.1).

```rust
/// A handle used by the procedure to drive the UI and record results.
#[derive(Clone, Debug)]
pub struct Context {
    /// Cancelled by the application at shutdown, which unblocks any prompt this
    /// context is waiting on.
    cancel: CancellationToken,

    /// The run's measurements, shared because `Context` is cloned per section.
    characterisation: Arc<Mutex<Characterisation>>,

    /// The section this context's steps are appended to.
    parent: StepPath,

    /// The step tree.
    root: Arc<Mutex<Section>>,

    /// Whether the results have been saved yet, so the first save can say where
    /// they're going (§10.3). Shared for the same reason as `characterisation`.
    saved: Arc<AtomicBool>,

    /// The readings published by the hardware poll task.
    snapshots: watch::Receiver<Option<Snapshots>>,
}

impl Context {
    /// Runs `f` inside a new section, and marks the section done when it ends.
    ///
    /// The context passed to `f` is parented to the new section, so any steps
    /// it emits are nested beneath it. On error the section is marked failed
    /// and the error propagates. Whatever `f` returns is passed back, so a
    /// section can hand its measurements to the caller that records them.
    pub async fn section<F, Fut, T>(
        &self,
        title: impl Into<String>,
        f: F,
    ) -> Result<T, ProcedureError>
    where
        F: FnOnce(Context) -> Fut,
        Fut: Future<Output = Result<T, ProcedureError>>;

    /// Waits for the user to confirm that something is the case.
    ///
    /// A gate rather than a question (§9.3): it returns once they have, and the
    /// only way past it otherwise is quitting.
    pub async fn confirm(&self, prompt: impl Into<String>) -> Result<(), ProcedureError>;

    /// Asks the user for a value and waits until they enter a valid one.
    ///
    /// A value that doesn't parse gets its parse error beside the prompt.
    pub async fn input<T>(
        &self,
        prompt: impl Into<String>,
        unit: Option<&str>,
    ) -> Result<T, ProcedureError>
    where
        T: FromStr,
        T::Err: Display;

    /// Adds a labelled measurement to the step list.
    pub fn measurement(&self, label: impl Into<String>, value: impl Display);

    /// Records measurements into the run's results.
    ///
    /// This only mutates memory. Call `save` to write them to disk.
    pub fn record(&self, f: impl FnOnce(&mut Characterisation));

    /// Writes the run's results to disk.
    ///
    /// Failures are reported as a failed step and logged, but never abort the
    /// procedure.
    pub fn save(&self);

    /// The most recent readings.
    ///
    /// Always `Some` inside the procedure: it isn't started until the first
    /// snapshot has arrived.
    pub fn snapshot(&self) -> Snapshots;

    /// Adds a line of text.
    pub fn text(&self, text: impl Into<String>);

    /// Waits until `predicate` holds for a snapshot, showing a spinner.
    ///
    /// This is how the procedure waits on the chamber — e.g. for the pressure
    /// to fall below the TMP's maximum backing pressure — using the readings
    /// the poll task is already taking rather than issuing its own.
    pub async fn wait_for(
        &self,
        label: impl Into<String>,
        predicate: impl Fn(&Snapshots) -> bool,
    ) -> Result<(), ProcedureError>;

    /// Runs `f`, showing a spinner labelled `label` until it completes.
    ///
    /// Pushes a text step and finishes it when `f` returns; a text step that
    /// hasn't finished is what a spinner is (§9.1).
    pub async fn waiting<F, Fut, T>(&self, label: impl Into<String>, f: F) -> Result<T, ProcedureError>
    where
        F: FnOnce() -> Fut,
        Fut: Future<Output = Result<T, ProcedureError>>;

    // Private helpers. Every method above is built from these three, and they
    // are the only places that take the step tree's lock.

    /// Appends a step beneath this context's section and returns its path.
    fn push(&self, kind: StepKind) -> StepPath;

    /// Applies `f` to the kind of the step at `path`.
    ///
    /// Used to write a parse error back into an input step before
    /// re-prompting, or the value it accepted once one parses.
    fn update(&self, path: &[usize], f: impl FnOnce(&mut StepKind));

    /// Sets the step's status and `finished_at`.
    fn finish(&self, path: &[usize], status: StepStatus);
}
```

Every `await` inside `Context` selects on `self.cancel.cancelled()` and returns
`ProcedureError::Cancelled`. The synchronous methods take the relevant lock,
mutate, and release it; none can fail in a way the caller must handle, which is
why they don't return `Result`.

```rust
#[derive(Debug, Error)]
pub enum ProcedureError {
    #[error("cancelled")]
    Cancelled,
    #[error("hardware error: {0}")]
    Hardware(#[from] HardwareError),
    #[error("python error: {0}")]
    Python(#[from] PythonError),
}
```

`Cancelled` is what every waiting method returns once the token fires. There's
no variant for the procedure's own checks — a reading outside a plausible
range, say — because the stubs make none; add one with the first that does.
Refusals by the hardware, such as a current above the cap, are already
`HardwareError`s.

### 11.2 The procedure itself

No `Stage` type, no registry, no function pointers. The procedure is one async
function calling others, and `ctx.section` is what makes the nesting visible:

```rust
/// Characterises a filament.
///
/// The top-level sections of the run, in order. Each one is an ordinary async
/// function, so the procedure reads as the sequence of things that happen.
pub async fn characterise(ctx: Context, hardware: Hardware) -> Result<(), ProcedureError> {
    ctx.section("Preparing", |ctx| prepare(ctx, hardware.clone())).await?;
    ctx.section("Pumping down chamber", |ctx| pump_down(ctx, hardware.clone())).await?;
    ctx.section("Measuring cold resistance", |ctx| measure_cold_resistance(ctx, hardware.clone())).await?;
    ctx.section("Spinning down TMP", |ctx| spin_down(ctx, hardware.clone())).await?;
    ctx.section("Finishing", |ctx| finish(ctx, hardware.clone())).await?;
    Ok(())
}
```

Sections nest freely: any of those functions can call `ctx.section` again for a
sub-section, or just push steps. Each takes the `Hardware`, which is how a
section reads an instrument faster than the once-a-second snapshot — sampling in
a loop, or waiting on a condition inside `ctx.waiting`. `ctx.wait_for` is for
conditions the snapshot can answer. Control flow is ordinary Rust — a loop over
sweep points, an early return on a failed check, a conditional section —
which is the point of doing it this way rather than through a list of stages.

### 11.3 The stub bodies

These exercise every step kind, every interaction, the save path and the Python
path. Real logic is a `TODO`. Only the cold resistance is measured; the sweep of
the heating current waits for the real procedure. `MAXIMUM_HEATING_CURRENT_AMPS`
is held at 100 mA until then, so nothing the stubs do can heat a filament.

```rust
async fn pump_down(ctx: Context, hardware: Hardware) -> Result<(), ProcedureError> {
    ctx.confirm("Confirm that the roughing pump is running").await?;

    ctx.wait_for("Waiting for chamber to reach TMP operating pressure", |s| {
        s.vacuum.pressure.value < TMP_MAXIMUM_BACKING_PRESSURE_MBAR
    })
    .await?;

    hardware.vacuum.set_tmp_running(true).await?;
    ctx.text("Turned on the TMP");

    // TODO: wait on the real filament operating pressure rather than the TMP
    // reaching speed.
    ctx.wait_for("Waiting for TMP to reach speed", |s| {
        s.vacuum.tmp_current_rotation_speed >= s.vacuum.tmp_target_rotation_speed
    })
    .await?;

    ctx.measurement(
        "Base pressure",
        format!("{:.1e} mbar", ctx.snapshot().vacuum.pressure.value),
    );
    Ok(())
}
```

The rest:

- `prepare` asks for the filament identifier (`ctx.input` → `ctx.record` →
  `ctx.save`) before anything else — the first save is what tells the operator
  where the results are being written — then calls
  `set_heating_voltage_limit(MAXIMUM_HEATING_VOLTAGE_VOLTS)` once so the channel runs
  in constant current, and confirms the filament is mounted and the chamber is
  sealed.
- `measure_cold_resistance` runs a sub-section per polarity, `Forward` then
  `Reverse`. Each disables the output before switching the relays, as
  `set_polarity` requires; sets `COLD_RESISTANCE_CURRENT_AMPS`, enables the
  output and lets it settle; takes `SAMPLE_COUNT` samples of voltage and
  current; disables the output; and summarises each set with
  `python::mean_and_standard_error`, showing the results as measurement steps.
  The sub-section returns its two `Measurement`s, which the caller records and
  saves. This is the one stub that runs the whole measurement pattern end to
  end, so make it the reference for the others.
- `spin_down` turns the TMP off and waits for its rotation speed to reach zero.
- `finish` zeroes the supply, returns the relays to `Polarity::Nil`, and saves a
  final time.

---

## 12. Python integration

Statistics and uncertainty propagation are done in Python with the
`uncertainties` package, so the crate ships scripts and expects a virtual
environment beside them.

Each script has **its own interface**: one JSON object on stdin, one JSON object
on stdout. Nothing passes the whole `Characterisation` struct to Python — the
Rust side sends the numbers a particular calculation needs and stores what comes
back.

The Rust types are the source of truth for those objects. Every input and output
type derives `Serialize`, `Deserialize` and `schemars::JsonSchema`, with
`#[serde(deny_unknown_fields)]`. The schemas generated from them are committed
as `python/schemas/<script>.input.json` and `<script>.output.json`, and the
`schemas_are_up_to_date` test in `python.rs` fails if they differ from the types
(run it with `UPDATE_SCHEMAS=1` to rewrite them). `python/script_io.py` gives
every script two helpers: `read_input(script_name)` reads stdin and validates it
against the input schema, exiting with the error on stderr if it doesn't match,
and `write_output(obj)` writes with `allow_nan=False`, since `NaN` isn't valid
JSON and `serde_json` rejects it.

### 12.1 Layout and constants

```rust
/// The directory holding the analysis scripts and their virtual environment.
///
/// Resolved at compile time from the crate root, since the binary is run from
/// the source tree. If the compiled path doesn't exist at run time, fall back
/// to `./python` relative to the working directory.
const PYTHON_DIR: &str = concat!(env!("CARGO_MANIFEST_DIR"), "/python");

/// The interpreter inside the virtual environment.
const VENV_PYTHON: &str = ".venv/bin/python";
```

`python/requirements.txt` pins `jsonschema`, `numpy`, `scipy` and `uncertainties`,
and `python/.python-version` pins the Python version. The environment is created
with uv, which respects `.python-version` where `python3 -m venv` would use
whichever `python3` is on the `PATH`. `--directory python` makes uv look for the
file there. A comment at the top of `python.rs` states the one-off setup:

```
uv venv --directory python
uv pip install --directory python -r requirements.txt
```

### 12.2 Start-up check

Before `ratatui::init()`, so failures print normally rather than into the
alternate screen:

1. Check `PYTHON_DIR` resolves to an existing directory, falling back as above.
2. Check the interpreter at `<python dir>/.venv/bin/python` exists.
3. Run `<interpreter> -c "import jsonschema, numpy, scipy, uncertainties"` with a short timeout
   (`PYTHON_CHECK_TIMEOUT`, 10 s) and require exit status 0.

Any failure aborts start-up with an error naming the missing piece **and the two
commands above**, so the operator can fix it without reading the source. Log the
resolved interpreter path with `info!` on success.

### 12.3 Invocation

```rust
/// Runs a script from the crate's `python` directory.
///
/// `input` is written to the script's stdin as JSON. The script is expected to
/// print a single JSON object on stdout, which is deserialised into `O`.
/// Anything it prints on stderr is logged.
pub async fn run_script<I: Serialize, O: DeserializeOwned>(
    script: &str,
    input: &I,
) -> Result<O, PythonError>;

/// The mean and standard error of a set of samples.
///
/// Wraps `mean_and_standard_error.py`, which is the calculation behind every
/// `Measurement` (§10.1).
pub async fn mean_and_standard_error(samples: &[f64]) -> Result<(f64, f64), PythonError>;
```

- Uses `tokio::process::Command` with the venv interpreter, never the system
  `python3`, and never a shell.
- Spawns the script with stdin piped, writes the serialised input, and **drops
  the stdin handle before waiting**, so the script's `json.load(sys.stdin)` sees
  end-of-file rather than blocking until the timeout.
- Wrapped in `tokio::time::timeout(PYTHON_TIMEOUT, ...)`; a script that hangs
  must not hang the procedure.
- A non-zero exit status, a timeout, or unparseable stdout are all errors
  carrying the script name and the captured stderr.
- `PythonError` is a `thiserror` enum.

### 12.4 The first script

`python/mean_and_standard_error.py` reads `{"samples": [...]}` on stdin and
prints `{"value": <mean>, "uncertainty": <standard error>}`. It imports
`uncertainties` even though the mean and standard error don't strictly need it,
so the venv is exercised on the same path as the real propagation. Resistance
and its propagated uncertainty are calculated by `cold_resistance_point.py` and
`cold_resistance_fit.py` beside it (`2_COLD_RESISTANCE.md` 3.3 and 3.4).

---

## 13. Application state

```rust
#[derive(Debug)]
struct App {
    /// The step tree, shared with the procedure task.
    root: Arc<Mutex<Section>>,

    /// The most recent readings, or `None` before the first poll.
    snapshots: Option<Snapshots>,

    /// When the application started.
    start_time: Instant,

    /// Scroll position of the steps list.
    steps_state: StepsState,
}

/// Why the application's event loop stopped, returned by `App::run`.
///
/// Whatever the reason, `main` then cancels the procedure, waits for it, and
/// puts the filament system into a safe state — in that order, and before
/// anything waits on the operator (§16).
#[derive(Debug)]
enum Shutdown {
    /// The procedure finished, the operator quit, or a signal asked us to stop.
    Normal,

    /// The run failed. The message is already shown as a failed step; this copy
    /// is what `main` reports once the terminal is restored.
    Error(String),

    /// The procedure task panicked. `ratatui::init`'s panic hook has already
    /// restored the terminal, so there's nothing left to show the error on.
    Panicked(String),
}
```

`App::run` returns the reason rather than storing it, so there's no shutdown
state on `App` and no "acknowledged" flag to track: after a failure, `main`
calls `App::acknowledge`, a small second loop that shows the final state of the
run until any key is pressed.

The `None` snapshot is the only start-up state. Once the first one is handled,
it is `Some` and stays that way — a poll failure never clears it, it retries and
then becomes fatal (§8.1). The procedure doesn't start until that first snapshot
exists either: `main` spawns it, and its runner's first act is to wait on its own
watch receiver for `Some`. So nothing runs against instruments that haven't
answered, without `App` having to hold the procedure's inputs just to hand them
on.

Until then, the vacuum and filament blocks render their border and title with a
centred `Waiting for readings…` in `SUBTLE_TEXT_STYLE` — the same treatment the
existing binary gives `Measuring pressure...`. Each block takes
`Option<&Snapshot>` and handles the `None` case itself, so there is exactly one
empty-state path per block and no placeholder values anywhere.

---

## 14. UI

```
┌ Vacuum ─────────────┐┌ Filament ────────────┐┌ Run ───────────────┐
│ Pressure:  1.2e-05 m││ Current:    1.850 A  ││ Elapsed:  00:12:31 │
│ TMP:       Running  ││ Polarity:   Forward  ││ Section:  Pumping… │
│ Speed:     1500/1500││ Output:     Enabled  ││ Status:   Running  │
│ Current:   0.42 A   ││ Voltage:    482.1 mV ││                    │
└─────────────────────┘└──────────────────────┘└────────────────────┘
┌ Steps ────────────────────────────────────────────────────────────┐
│ ✔ Preparing                                            00:00:42   │
│   ✔ Filament: W-0007                                              │
│   ✔ Confirm that the chamber is sealed                            │
│ ✔ Pumping down chamber                                 00:06:05   │
│   ✔ Confirm that the roughing pump is running                     │
│   ✔ Waiting for chamber to reach TMP operating pressure   3.1 s   │
│   ✔ Turned on the TMP                                             │
│   ✔ Base pressure: 2.4e-06 mbar                                   │
│ ⟳ Measuring cold resistance                            00:00:08   │
└───────────────────────────────────────────────────────────────────┘
 [↑/↓] Scroll   [Enter] Confirm   [Esc] Quit
```

```rust
let [top, steps, shortcuts_bar] = Layout::vertical([
    Constraint::Length(6),
    Constraint::Min(0),
    Constraint::Length(1),
])
.areas(area);

let [vacuum, filament, run] = Layout::horizontal([
    Constraint::Min(24),
    Constraint::Min(24),
    Constraint::Length(24),
])
.areas(top);
```

The run block's `Section` row is the title of the last root-level section in the
tree, since there's no stage list to count against.

Reuse the style constants from the existing binary verbatim —
`BLOCK_TITLE_STYLE`, `CONFIRMATION_STYLE`, `ERROR_STYLE`, `SUBTLE_TEXT_STYLE`,
`VARIABLE_STYLE` — and the same idiom of a label in default style followed by
the value in `VARIABLE_STYLE`. Blocks are `Block::bordered()` with
`Padding::symmetric(2, 1)` where there's room; the steps block can use
`Padding::symmetric(2, 0)` to save vertical space.

Formatting: pressure `{:.1e} mbar`; heating current `{:.3} A`; filament voltage
in mV to one decimal; elapsed times `HH:MM:SS`, or `{:.1} s` under a minute. No
resistance is shown anywhere in the UI (§7.1). The filament block has room for
another row; a later version adds emission current there (§17).

Implement each block as a small struct with a `Widget` impl over a borrowed
snapshot, matching `impl Widget for &State` in the existing binary.

### 14.1 The steps widget

```rust
/// Scroll position of the step list.
#[derive(Debug, Default)]
pub struct StepsState {
    /// If the view follows the end of the list as steps are added.
    follow: bool,

    /// The index of the first visible line.
    offset: usize,
}
```

- Lines are rebuilt from the tree every frame. That's fine: ratatui diffs
  buffers, so an unchanged frame costs no terminal I/O, and the running step's
  spinner means most frames change anyway.
- When `follow` is true (the default), `offset` is pinned so the last line is
  visible. Any upward scroll sets `follow = false`; `End`, or scrolling back to
  the bottom, sets it true again.
- Clamp `offset` to `lines.len().saturating_sub(height)` every frame, since the
  content grows and the terminal can be resized under it.
- Lines are ellipsified to the block width, never wrapped (§9.4). No horizontal
  scrolling.
- No scrollbar. Scrolling alone is enough.
- A pending step must always be visible: if `Section::pending_mut` finds one
  while `follow` is false, scroll to it and re-enable following.

---

## 15. Input handling

Key events are routed in this order:

1. `Ctrl+C` — always quits immediately.
2. If `Section::pending_mut` returns a step, it consumes the event:
   - **Confirm**: `Enter` confirms; `Esc` → quit. There's no key for "no" —
     a confirmation is a gate, not a question (§9.3).
   - **Input**: printable characters append to the buffer; `Backspace` deletes;
     `Enter` takes the responder and sends the buffer; `Esc` → quit.
   - **Question**: `y` answers yes and `n` answers no; `Esc` → quit. `Enter`
     does nothing, so one left over from the confirmations before it can't
     answer by accident.
3. Otherwise:
   - `↑` / `↓`, `PgUp` / `PgDn`, `Home` / `End` — scroll the step list.
   - `q` / `Esc` — quit.

While `App::acknowledge` is showing a failed run, any key ends it, and the
shortcuts bar reads `[Any key] Exit`. By then the filament system is already
safe (§16).

Only handle `event.is_press()`, as the existing binary does, so key repeats on
some terminals don't double-fire. The shortcuts bar text changes with context,
again matching the existing binary.

---

## 16. Errors, shutdown and cleanup

`main` runs the start-up checks before the terminal is touched, then the event
loop, then the shutdown sequence — which runs **however the loop ended**,
including when `App::run` itself fails (a poisoned lock, or a draw that fails
because the terminal has gone). That's why the sequence lives in `main` rather
than in the loop: the loop can't guarantee its own cleanup.

`main` returns an `ExitCode` and reports errors itself, with `Display`, rather
than returning the `Result`: Rust would report that with `Debug`, which drops
the message — and for a `PythonError::Environment` the message is what tells
the operator which commands to run.

### 16.1 What ends the loop

- The operator quitting: `q` or `Esc` with nothing pending, `Esc` at a prompt,
  or `Ctrl+C` at any time. In raw mode `Ctrl+C` arrives as a key rather than
  SIGINT, so it goes through the same path.
- SIGHUP (the terminal window closing) and SIGTERM (`kill`). By default either
  would end the process on the spot, with no cleanup; the loop handles them and
  shuts down like a quit. `kill -9` can't be handled.
- The procedure finishing (`Normal`) or failing (`Error`), or a fatal hardware
  failure (`Error`). A failure is added as an error step at the end of the list,
  where the operator is looking.
- The procedure panicking (`Panicked`). The task is wrapped in `catch_unwind`, so
  a panic is reported instead of the task dying silently and leaving the
  application waiting for an event that never comes.

### 16.2 The sequence

1. **Cancel the token.** Any pending `confirm`, `input`, `wait_for` or `waiting`
   returns `Cancelled`, and the sections it was in finish `Failed`. A cancelled
   prompt also gives up its responder, so it stops counting as pending.
2. **Wait for the procedure**, for up to `SHUTDOWN_TIMEOUT` (2 s), then abort
   it. Cancelling doesn't stop the procedure where it is: it stops at its next
   cancellation-aware await, and plain hardware calls such as
   `set_output_enabled(true)` don't watch the token. Cleaning up before it had
   stopped would race those calls, and one landing after the cleanup could turn
   the output back on. Waiting means **the cleanup always has the last word**.
   It also lets the runner's final save happen, so quitting mid-run leaves the
   results on disk. An aborted procedure can't save, which is why saves happen
   at every measurement rather than only at the end.
3. **`enter_safe_state`**, bounded by `CLEANUP_TIMEOUT` (5 s) so that a hung
   instrument can't stop the terminal being restored. It attempts every action
   and returns the first failure, so the operator can be warned.
4. **Read the TMP's state** afresh, bounded the same way. The last snapshot is
   stale if it's the vacuum side that failed.
5. **After an `Error` only**, show the final state of the run — with a step
   saying whether the filament system was made safe — and wait for any key. The
   filament is made safe *before* this, never after: a fatal hardware failure
   mid-measurement mustn't leave it powered while someone reads the error.
6. **Restore the terminal and report**: the results path, if the procedure got
   far enough to write it; a warning if the filament system may still be
   powered, with the reason; a note if the TMP is still running, or that it may
   be if its state couldn't be read (after a completed run the procedure has
   stopped it); and the error, with a non-zero exit.

The terminal may be gone by step 6 — that's what SIGHUP means — so nothing there
may panic on a failed write: the terminal is restored with `try_restore`, and
the report lines ignore write errors rather than using `println!`.

### 16.3 Panics

`ratatui::init` installs a panic hook that restores the terminal before
chaining to the previous hook, so a panic message isn't swallowed by the
alternate screen. A hook can't run the asynchronous cleanup, though. A panic in
the procedure task is caught and still gets the full sequence above, bar the
acknowledgement (the hook has already restored the terminal). A panic in the
application itself can't, which is why nothing there may panic and why every
fallible call returns an error instead.

The results are saved by the procedure runner, which owns the `Characterisation`
through `Context` and saves on every exit path that lets it return — so `main`
doesn't need a save of its own.

---

## 17. Extension points for emission current

Emission current is out of scope for this version, but the structure must make
adding it a local change. Leave a short `// Later: emission current` comment at
each of these points, and nowhere else:

1. `FilamentSystem` — a `get_emission_current` method, and its inclusion in
   `snapshot`.
2. `FilamentSnapshot` — an `emission_current` field.
3. `hardware/real.rs` — the instrument behind it, alongside the oscilloscope.
4. `ui/filament.rs` — one more row in the block, which has the space for it.
5. `results.rs` — one more `Measurement` field on `Characterisation`.
6. `procedure/characterisation.rs` — one more `ctx.section(...)` line in
   `characterise` and one more async function.

If adding emission current would require touching anything outside that list,
the structure is wrong — fix it now rather than working around it later.

---

## 18. Code style

Match the attached code exactly. In particular:

- **Australian/British spelling in prose and comments** — "initialise",
  "characterise", "behaviour". Identifiers follow suit.
- **Doc comments on every public item and every struct field**, written as
  sentences with full stops. Multi-paragraph where a hardware quirk needs
  explaining, with the extra paragraphs after a blank `///` line.
- **Fields and variants in alphabetical order**, as in `App` and `State`. Enum
  variants may be grouped under `// Section` comments (as `AdcError` does) and
  are alphabetical or numerical within a group.
- **Methods**: `new` first, then public methods roughly alphabetically, then
  private helpers. Reads are `get_*`, writes are `set_*`, as in `host`.
- **`thiserror` for all domain errors**, messages lowercase and unpunctuated,
  `#[from]` for wrapped errors; `type AnyError = Box<dyn std::error::Error>` in
  the binary only.
- **`error!` immediately before returning an `Err`**, including the value that
  caused it.
- **Comments explain why, not what** — especially anything protecting hardware.
  Safety-critical constants carry a doc comment citing the manual and any extra
  margin applied, in the manner of `TMP_MAXIMUM_BACKING_PRESSURE_MBAR`.
- Units in names and doc comments (`_mbar`, `_amps`, `in hertz`).
- `std::sync::Mutex` for the shared step tree and results, never held across an
  `.await`; `tokio::sync::Mutex` only where a lock genuinely spans one.
- rustfmt defaults; `cargo clippy --all-targets -- -D warnings` must be clean.
- No `unwrap()` outside tests except where an invariant has just been asserted,
  and then with a comment saying which.
- Python: PEP 8, type hints, a module docstring saying what the script consumes
  and prints.

Reuse rather than redefine: import `Pressure`, `PressureUnit`, `AdcError`,
`TmpError` and `Polarity` from `host`, and lift
`TMP_MAXIMUM_BACKING_PRESSURE_MBAR` (12.0, with its existing comment) into the
new crate's constants alongside `MAXIMUM_HEATING_CURRENT_AMPS` and
`MAXIMUM_HEATING_VOLTAGE_VOLTS`.

---

## 19. Build order

Each step should compile, pass clippy, and run.

1. Hoist the shared dependencies to `[workspace.dependencies]` (§4.1) and
   confirm `host` and the existing binary build unchanged.
2. Crate skeleton, `Arguments`, `init_logging`, terminal init/restore, panic
   hook, empty app loop that quits on `q`.
3. `python.rs` plus `requirements.txt` and `mean_and_standard_error.py`; the
   start-up check fails helpfully with no venv and passes with one.
4. `steps.rs`: `Step`, `Section`, the `StepKind` constructors, paths, `render`,
   and the steps widget driven by a hard-coded tree. Scrolling, indentation,
   clipping, ellipsifying and following all work.
5. `hardware/`: traits, snapshots, mocks. `--mock` is wired up;
   `RealVacuumSystem` follows, then the `host` stubs and the filament adapter.
6. Poll task and watch channel, the empty state, then the three top blocks
   showing live mock data.
7. `results.rs`: `Measurement`, `Characterisation`, `save`.
8. `Context` and the procedure, with the stub bodies. Confirm and input
   round-trip, `wait_for` resolves off the watch channel, saves land on disk,
   and `measure_cold_resistance` gets a real answer back from Python.
9. Shutdown, cancellation, fatal hardware failure and `enter_safe_state` on
   every path.

## 20. Acceptance criteria

- `cargo run -p characteriser -- --mock` runs end to end with no
  hardware: the blocks show the empty state until the first poll, every section
  executes, the confirm and input prompts accept keyboard input, and the step
  list scrolls, indents and follows.
- Narrowing the terminal ellipsifies long step lines rather than wrapping them,
  a section's elapsed time stays visible with its title ellipsified, and the
  scroll offset stays valid across the resize.
- Running without the virtual environment fails before the TUI starts, with a
  message naming the two commands that create it.
- `cargo run -p characteriser -- /dev/tty.usbmodem11201 1 001` reads
  real pressure and TMP values into the top blocks, logging at start-up that the
  filament system is mocked.
- `out/characterisation-<timestamp>.json` exists after a run, parses as JSON,
  carries the filament identifier, and is present and valid even when the run is
  quit half way through or fails.
- `measure_cold_resistance` shows a value and an uncertainty that came back from
  Python, proving the round trip.
- Quitting at any point — including while a prompt is pending — restores the
  terminal, logs the shutdown, and runs `enter_safe_state`, leaving the relays
  de-energised and the TMP running.
- Three consecutive poll failures end the run with an error step, cleanup and a
  non-zero exit; a single failure only logs a warning.
- Nothing is ever printed to stdout/stderr while the TUI is on screen; all
  diagnostics land in `out/app.log`.
- `cargo clippy --all-targets -- -D warnings` and `cargo fmt --check` are clean.

## 21. Future work (do not implement)

- Emission current measurement (§17).
- Real bodies for the `host` `PowerSupply` and `Oscilloscope` methods.
- The real measurement pattern: n samples per quantity, both polarities, a
  `Measurement` per recorded field.
- Resistance and its propagated uncertainty, in a Python script beside
  `mean_and_standard_error.py`.
- Chart steps, which would mean switching the step list to the oversized-buffer
  rendering described in §9.4.
- Replaying a recorded run against the mock for UI development.
- Resuming a procedure from a given section.

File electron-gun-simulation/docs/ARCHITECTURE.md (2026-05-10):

# Architecture

This document specifies the code structure, crate layout, and interfaces between components. It is the authoritative reference for how the codebase is organised. `PHYSICS.md` specifies _what_ the solver computes; this document specifies _how_ the code is arranged and how components communicate.

## 1. Overview

The project contains a Cargo workspace with two Rust crates and a Vite-based TypeScript web application:

```
sem-gun-sim/
├── CLAUDE.md
├── docs/
│   ├── PHYSICS.md
│   ├── ARCHITECTURE.md         # this file
│   └── UI.md
├── crates/
│   ├── Cargo.toml              # workspace root
│   ├── solver/                 # pure Rust, generic Laplace solver
│   │   ├── Cargo.toml
│   │   ├── src/
│   │   └── tests/
│   └── wasm-api/               # thin wasm-bindgen wrapper, gun-aware
│       ├── Cargo.toml
│       └── src/
└── web/                        # Vite + TypeScript application
    ├── package.json
    ├── index.html
    ├── src/
    └── public/
```

Three layers, each with a clear responsibility:

1. **`solver`** — pure Rust library. Knows about grids, stencils, sparse matrix assembly, and Cholesky factorisation. Knows nothing about electron guns. Native-testable with `cargo test`. No wasm dependencies.
2. **`wasm-api`** — thin Rust crate exposed to JavaScript via `wasm-bindgen`. Knows about `GunParameters`, electrode rasterisation, and the JS-facing API. Calls into `solver` for the potential solve and E-field extraction. Depends on `solver`.
3. **`web`** — Vite-based TypeScript application. Knows about UI state, sliders, visualisation, and the debounce/preview strategy. Consumes the wasm package.

Data flows one direction per user interaction: slider change in TS → `GunParameters` struct → wasm call → `GunSolution` back → render.

## 2. Rationale for the two-crate split

The `solver` and `wasm-api` are deliberately separate crates:

- **Native testability.** `solver` is a normal library crate (`crate-type = ["lib"]`) and runs under `cargo test` natively on any target. Tests run in milliseconds with a real debugger. `wasm-api` is a `cdylib` crate (required by `wasm-pack`), which cannot be depended on by other Rust crates — so solver logic placed there would not be importable for testing.
- **Dependency isolation.** `wasm-api` depends on `wasm-bindgen`, `js-sys`, etc., which only compile for `wasm32-unknown-unknown`. Keeping the solver free of these means it compiles cleanly for any target with no `#[cfg(target_arch = "wasm32")]` guards.
- **Layering.** Solver logic vs. JS-boundary logic are genuinely different concerns. A future CLI tool, native GUI, or Python binding via PyO3 would depend on `solver` and write a new thin wrapper — no untangling of wasm annotations from numerics.

## 3. The `solver` crate

### 3.1 Responsibility

Solves Laplace's equation on a 2D axisymmetric grid via sparse direct solve, given a grid of initial potential values and a mask marking which points are fixed (Dirichlet) versus free. Returns the solved potential grid. Also provides E-field extraction from a solved potential grid.

`solver` has no knowledge of electron guns, filaments, Wehnelts, or anodes. It sees only grids, masks, and numbers.

### 3.2 Dependencies

- **`faer`** — sparse Cholesky factorisation. This is the only significant dependency of the solver crate.

### 3.3 Core types

```rust
/// A 2D grid of f64 values stored in row-major order with z as the row index
/// and r as the column index. Layout matches PHYSICS.md §2.2.
pub struct Grid {
    pub n_r: usize,
    pub n_z: usize,
    pub h_m: f64,         // grid spacing in metres (dr = dz = h)
    pub data: Vec<f64>,   // length n_r * n_z, indexed as data[i_z * n_r + i_r]
                          // no unit suffix: may hold V, V/m, or other quantities
}

/// Per-point mask indicating whether the solver should update this point.
pub enum Cell {
    Free,
    Fixed,
}

pub struct Mask {
    pub n_r: usize,
    pub n_z: usize,
    pub data: Vec<Cell>, // same indexing as Grid
}
```

The `Grid` is used for both input (initial V with Dirichlet values set on `Fixed` points) and output (solved V). E-field grids (`E_r`, `E_z`) are also `Grid` values.

### 3.4 Core functions

```rust
pub struct SolverResult {
    pub n_free: usize,             // number of Free points solved for
}

/// Solves Laplace's equation in place on `potential`, computing the
/// values at Free points as marked in `mask`. Uses sparse Cholesky
/// factorisation as specified in PHYSICS.md §4.
///
/// The function validates the following before solving and returns the
/// corresponding SolverError if any check fails (without modifying the
/// potential grid):
/// - `potential` and `mask` have the same dimensions.
/// - The grid has at least 3 points in each direction.
///
/// The caller is responsible for:
/// - Pre-setting Dirichlet values on Fixed points in the potential grid.
/// - Marking the outer boundary (i_r = N_r-1, i_z = 0, i_z = N_z-1) as
///   Fixed (any potential is allowed). The axis (i_r = 0) should be Free
///   unless a point lies on an electrode.
pub fn solve_laplace_cylindrical(
    potential: &mut Grid,
    mask: &Mask,
) -> Result<SolverResult, SolverError>;

/// Computes E_r and E_z from a solved potential grid using the formulas
/// in PHYSICS.md §2.6. Returns (e_r, e_z) where both are Grid values with
/// the same dimensions as the input. Values are in V/m.
pub fn compute_electric_field(potential: &Grid) -> (Grid, Grid);
```

### 3.5 Error handling

```rust
pub enum SolverError {
    DimensionMismatch { grid: (usize, usize), mask: (usize, usize) },
    GridTooSmall { n_r: usize, n_z: usize },
    FactorisationFailed(String),
}
```

Use `thiserror` for the `Display` impl. No panics on runtime conditions — invalid input returns `Err`.

## 4. The `wasm-api` crate

### 4.1 Responsibility

Bridges `solver` to JavaScript. Translates a `GunParameters` struct from JS into the grid + mask representation the solver needs, invokes the solver, extracts E-fields, and packages the result for return to JS.

### 4.2 `GunParameters`

The parameters struct is the single source of truth for electron gun configuration. All dimensions are in **millimetres** (UI convention); the wasm-api crate converts to metres internally before calling the solver. All voltages are in volts, referenced to ground, unless otherwise stated.

```rust
#[wasm_bindgen]
#[derive(Clone, Copy)]
pub struct GunParameters {
    // --- Filament ---
    /// Radius of the filament, modelled as a solid disk centred on the
    /// z-axis. Because the simulation is axisymmetric, only the r ≥ 0
    /// half of the disk appears in the grid; the r < 0 half is implied
    /// by symmetry. In the (r, z) cross-section, the filament is a
    /// rectangle from r=0 to r=filament_radius, and from
    /// z=filament_z − thickness/2 to z=filament_z + thickness/2.
    pub filament_radius_mm: f64,
    /// Full thickness of the filament in z.
    pub filament_thickness_mm: f64,
    /// z-coordinate of the filament centre.
    pub filament_z_mm: f64,
    /// Voltage applied to the filament, referenced to ground
    /// (typically a large negative value, e.g. -10_000 V).
    pub filament_voltage_v: f64,

    // --- Wehnelt cylinder ---
    /// Outer radius of the cylindrical wall.
    pub wehnelt_outer_radius_mm: f64,
    /// Inner radius of the cylindrical wall (gives wall thickness).
    pub wehnelt_inner_radius_mm: f64,
    /// z-coordinate of the centre of the cylindrical wall.
    pub wehnelt_z_mm: f64,
    /// Total height of the cylindrical wall. The wall runs from
    /// z − height/2 to z + height/2. The open end is at the top
    /// (z + height/2); the cap is at the bottom (see below).
    pub wehnelt_height_mm: f64,
    /// Full thickness of the front cap plate. The cap sits at the
    /// bottom of the cylinder, from z − height/2 − cap_thickness
    /// to z − height/2. The aperture is in this cap.
    pub wehnelt_cap_thickness_mm: f64,
    /// Radius of the aperture in the front cap.
    pub wehnelt_aperture_radius_mm: f64,
    /// Voltage bias of the Wehnelt relative to the filament (typically
    /// a few hundred volts more negative, e.g. -200 V). The Wehnelt's
    /// absolute voltage is filament_voltage_v + wehnelt_bias_v.
    pub wehnelt_bias_v: f64,

    // --- Anode ---
    /// z-coordinate of the centre of the anode plate.
    pub anode_z_mm: f64,
    /// Full thickness of the anode plate in z.
    pub anode_thickness_mm: f64,
    /// Outer radius of the anode plate.
    pub anode_outer_radius_mm: f64,
    /// Radius of the aperture in the anode.
    pub anode_aperture_radius_mm: f64,
    /// Voltage applied to the anode, referenced to ground
    /// (typically 0 V / ground; defaults to 0 V).
    pub anode_voltage_v: f64,
}
```

Conventions:

- z increases upward. The Wehnelt's open end is always at the top (higher z) and its cap with aperture is at the bottom (lower z). The filament enters from the top and sits inside the cup. The beam exits downward through the cap aperture toward the anode. Typical z ordering: `anode_z_mm < wehnelt_z_mm − wehnelt_height_mm/2 < wehnelt_z_mm < filament_z_mm`.
- All electrodes use centre z-position + full thickness/height. Rasterisation computes the z-extent as ±thickness/2 (or ±height/2) from the centre. The Wehnelt cap is the one exception: it sits below the cylinder, from `wehnelt_z_mm − wehnelt_height_mm/2 − wehnelt_cap_thickness_mm` to `wehnelt_z_mm − wehnelt_height_mm/2`.
- Geometric consistency is validated in `wasm-api` before rasterisation. Validation failures are returned as errors through the API.

### 4.3 Rasterisation

Rasterisation converts `GunParameters` into a `Grid` (with Dirichlet voltages set) and a `Mask` (marking Fixed vs Free points). The process is:

1. Convert all dimensions from mm to metres.
2. Determine the simulation domain: compute the bounding box of all electrodes, then extend by 3× the largest electrode dimension in each direction (per PHYSICS.md §3.2). This gives R_max and Z_max.
3. Choose h = min(smallest electrode dimension) / 10 per PHYSICS.md §2.1. Compute N_r and N_z from R_max, Z_max, and h.
4. Allocate a `Grid` (all zeros) and `Mask` (all `Free`).
5. Mark the outer boundary as `Fixed`: all points where i_r = N_r−1, i_z = 0, or i_z = N_z−1 are set to `Fixed` in the mask and 0.0 in the potential grid. (Points at i_r = 0 are left `Free` — they are axis points handled by the r=0 stencil, unless they happen to lie on an electrode.)
6. For each grid point, test whether its physical location (r, z) lies inside any electrode's (r, z) cross-section. Each electrode's cross-section is one or more axis-aligned rectangles:
   - **Filament:** a single rectangle. Point (r, z) is inside if `r ≤ filament_radius` AND `|z − filament_z| ≤ filament_thickness / 2`.
   - **Wehnelt wall:** a single rectangle. Point (r, z) is inside if `wehnelt_inner_radius ≤ r ≤ wehnelt_outer_radius` AND `wehnelt_z − wehnelt_height/2 ≤ z ≤ wehnelt_z + wehnelt_height/2`.
   - **Wehnelt cap:** a single rectangle (with the aperture excluded). Point (r, z) is inside if `wehnelt_aperture_radius ≤ r ≤ wehnelt_outer_radius` AND `wehnelt_z − wehnelt_height/2 − wehnelt_cap_thickness ≤ z ≤ wehnelt_z − wehnelt_height/2`.
   - **Anode:** a single rectangle (with the aperture excluded). Point (r, z) is inside if `anode_aperture_radius ≤ r ≤ anode_outer_radius` AND `|z − anode_z| ≤ anode_thickness / 2`.
7. If a point lies inside an electrode, set the mask to `Fixed` and set the potential grid value to the electrode's voltage. The Wehnelt's absolute voltage is `filament_voltage_v + wehnelt_bias_v`. If a point lies inside multiple electrodes (which should not happen for valid geometry), the last one checked wins.

All dimension comparisons use physical coordinates in metres.

### 4.4 `GunSolution`

The solution struct returned to JS. Contains the potential and field grids plus metadata. The solver-internal `Grid` and `Mask` types are not `#[wasm_bindgen]`-compatible, so this struct unpacks them into flat `Vec`s exposed to JS.

The `#[wasm_bindgen(getter_with_clone)]` attribute on the grid fields tells wasm-bindgen to auto-generate cloning getters for `Vec` types that can't be simply copied across the boundary. `Vec<f64>` fields become JS `Float64Array` properties, and `Vec<u8>` becomes `Uint8Array`. The `#[wasm_bindgen(readonly)]` attribute on each field prevents JS from setting them.

```rust
#[wasm_bindgen]
pub struct GunSolution {
    #[wasm_bindgen(readonly)]
    pub n_r: usize,
    #[wasm_bindgen(readonly)]
    pub n_z: usize,
    #[wasm_bindgen(readonly)]
    pub h_m: f64,                // grid spacing in metres

    // All grids are length n_r * n_z, row-major as per PHYSICS.md §2.2.
    // Accessing these from JS returns a copy (clone) of the data.
    #[wasm_bindgen(getter_with_clone, readonly)]
    pub potential_v: Vec<f64>,   // potential in volts
    #[wasm_bindgen(getter_with_clone, readonly)]
    pub e_r_v_per_m: Vec<f64>,  // radial E-field component in V/m
    #[wasm_bindgen(getter_with_clone, readonly)]
    pub e_z_v_per_m: Vec<f64>,  // axial E-field component in V/m
    #[wasm_bindgen(getter_with_clone, readonly)]
    pub mask: Vec<u8>,           // 0 = Free, 1 = Fixed; useful for UI overlays
}
```

Each access to a `Vec` field from JS (e.g. `solution.potential_v`) clones the data from wasm linear memory into a new JS-owned typed array. For our grid sizes (a few hundred thousand floats, ~1-2 MB) this takes microseconds. The TS code should cache the result rather than accessing the property repeatedly.
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

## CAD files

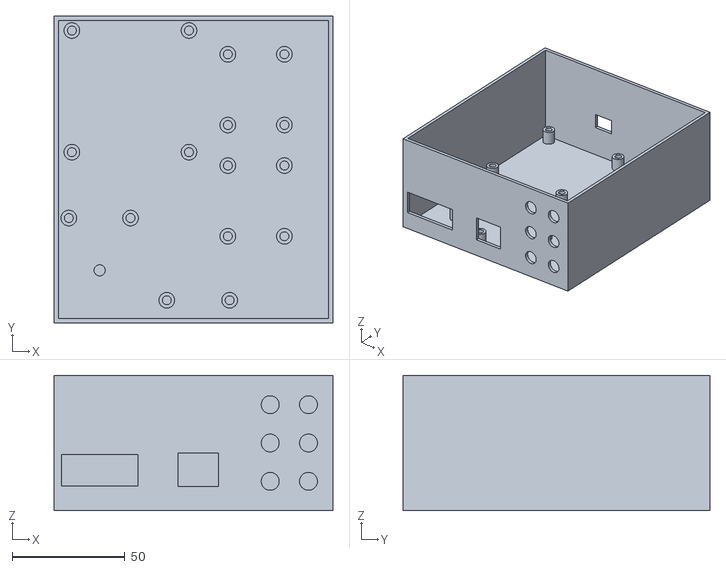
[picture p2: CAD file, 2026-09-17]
controller/case/Body.stl
123.7 x 136.3 x 60.0

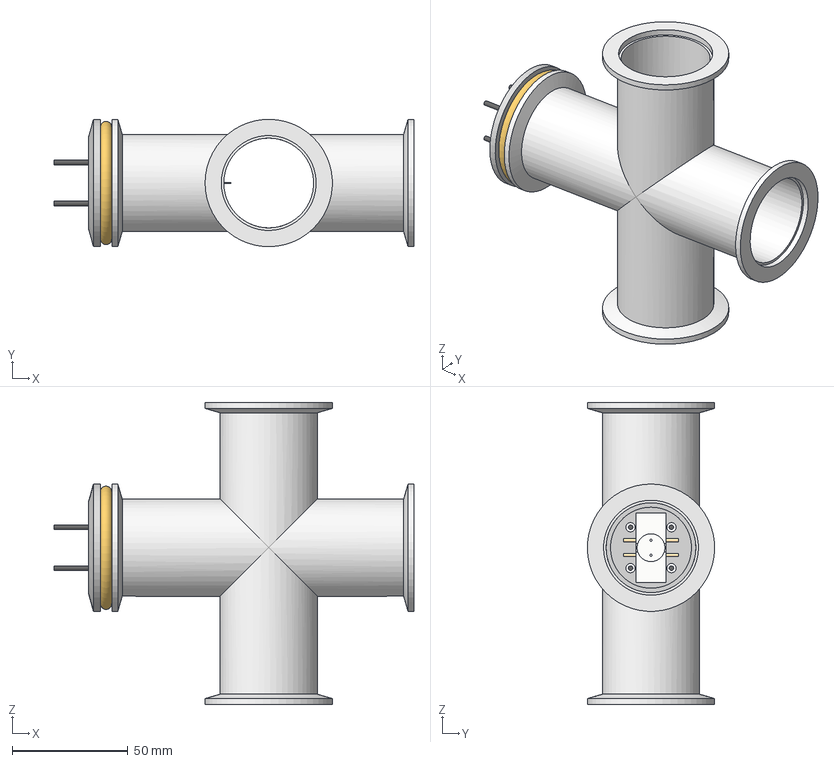
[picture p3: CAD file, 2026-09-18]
filament-characterisation/mount/Mount.step
155.5 x 55.0 x 130.5 mm
End cap
O-ring
Cross
Filament
M3 stud x 2
PEEK mount
Copper rod x 4
B61641CB-4F1C-420F-852D-4938F5350E26 x 4

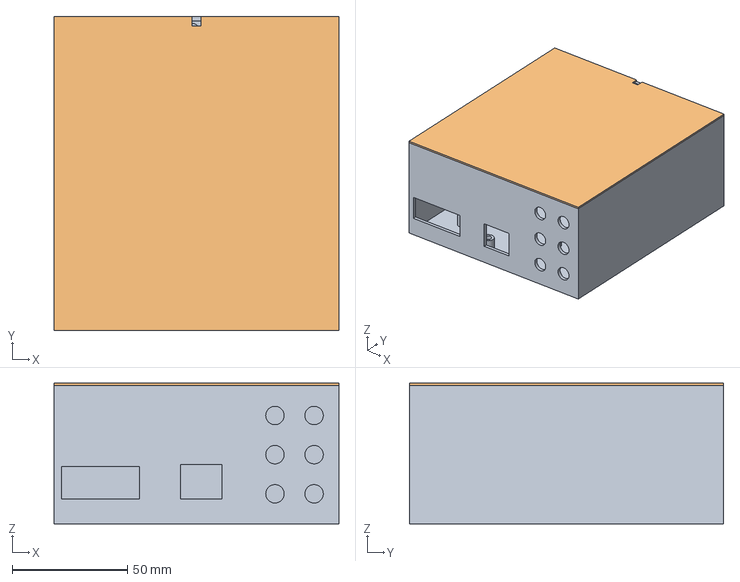
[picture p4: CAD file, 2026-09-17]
controller/case/Case.step
123.7 x 136.3 x 61.0 mm

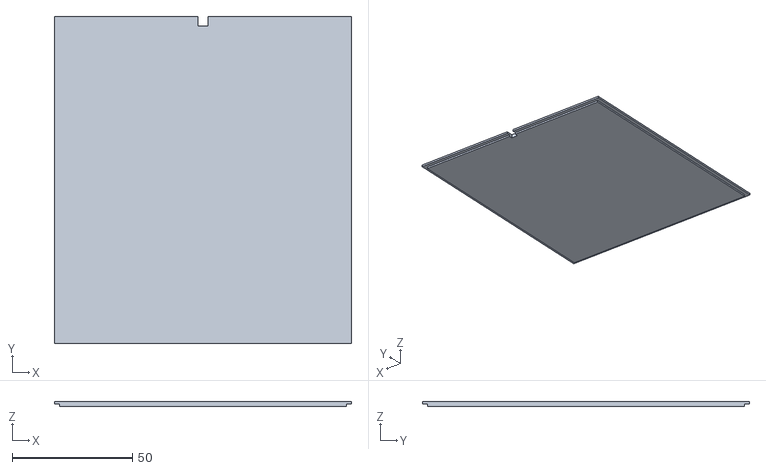
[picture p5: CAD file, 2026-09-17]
controller/case/Lid.stl
123.7 x 136.3 x 2.00

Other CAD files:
controller/case/Case.f3d
filament-characterisation/mount/Mount.f3d

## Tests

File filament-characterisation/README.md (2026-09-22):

This directory contains files relating to the hardware and software used to characterise tungsten filaments to be used in the SEM.

# Directory structure

- [`characteriser`](characteriser): A Rust crate containing the TUI that steps an operator through characterising a filament.
- [`mount`](mount): 3D models of the filament mount.

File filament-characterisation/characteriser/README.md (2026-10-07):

A Ratatui application that drives the vacuum rig and steps an operator through characterising a tungsten filament.

See [`../docs/1_ARCHITECTURE.md`](../docs/1_ARCHITECTURE.md) for the full specification.

# Requirements

- [Rust](https://rust-lang.org/)
- [uv](https://docs.astral.sh/uv/)

Statistics and uncertainty propagation are done by the scripts in [`python`](python), which need a virtual environment beside them. The Python version is pinned in [`python/.python-version`](python/.python-version). Create the environment once, from this directory, with uv, which reads that file and downloads the pinned Python if it isn't installed:

```
uv venv --directory python
uv pip install --directory python -r requirements.txt
```

The application checks for it at start-up and refuses to run without it, printing these same two commands.

# Running

1. Run `cargo run -- <device path> <ADC gauge number> <TMP address>`, e.g. `cargo run -- /dev/tty.usbmodem11201 1 001`.

To run against simulated hardware instead of the rig, run `cargo run -- --mock`.

To test the measurement on the bench without pumping down the chamber, e.g. against a precision resistor in place of a filament, add `--no-vacuum`. The vacuum hardware must still be connected, but the TMP is never started, and the chamber's pressure and the TMP aren't checked while current flows. See "Bench testing without vacuum" in [`../docs/2_COLD_RESISTANCE.md`](../docs/2_COLD_RESISTANCE.md) for how to read the result.

Diagnostics are written to `out/app.log` rather than the terminal. As with the vacuum control binary, the log level comes from `RUST_LOG`, which defaults to `error` — so run with `RUST_LOG=info` (or `debug`) to get anything useful in the file.

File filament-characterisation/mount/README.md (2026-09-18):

This directory contains a 3D model of the filament mount used during characterisation.

# Required hardware

- 4 x [2074-0-15-20-75-14-11-0
  Mill-Max terminals](https://au.mouser.com/en/ProductDetail/Mill-Max/2074-0-15-20-75-14-11-0)
- 4 x [35 mm lengths of 2 mm diameter copper rod](https://ausmakersupplies.com.au/products/copper-rod-3-17-x-300mm-cop-1-8-12)
- 2 x [50 mm M3 rods](https://www.bunnings.com.au/pinnacle-m3-x-50mm-stainless-steel-hex-head-bolts-and-nuts-8-pack_p0247302)
- 1 x [KF40 end cap](https://nanovactech.com/products/kf-nw-blank-stainless-steel-flanges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)
- 1 x [Loctite EA 1C](https://www.aircraftspruce.com.au/catalog/pnpages/01-15880.php)
- 1 x PEEK filament mount (see 3D model — order from PCBWay's CNC service)

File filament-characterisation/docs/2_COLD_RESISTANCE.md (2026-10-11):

# Cold resistance calculation steps

This document specifies the real body of `measure_cold_resistance` in `filament-characterisation/characteriser`, plus the changes it needs elsewhere in the crate and in `host`. It builds on `1_ARCHITECTURE.md`. Everything there still applies unless this document says otherwise: code style (§18), doc comments, saving after every measurement (§10.3), safe shutdown (§16), and "no statistics in Rust" (§2).

The filament is measured four-terminal, with current reversal, at a set of currents. The resistance at each current is plotted against $I^2$, and a weighted straight-line fit is extrapolated to $I = 0$ to give the cold resistance $R_0$ and its full uncertainty budget.

## Why extrapolating to $I^2 = 0$ gives $R_0$

Any current heats the filament, so every measured resistance is slightly above the cold resistance. At zero current there's no heating, but there's also no voltage to measure. The fit works around this by measuring where the signal is good and extrapolating back.

At each setpoint the filament settles where the electrical power going in equals the heat going out. Heat leaves in two ways.

**Conduction** along the wire into its mount follows Fourier's law: heat flows down a temperature gradient at a rate $q = -kA\,dT/dx$, where $k$ is the thermal conductivity and $A$ the cross-section. Take a length $L$ of wire carrying heat from the filament at $T$ to the mount at $T_0$, with no heat generated inside it. In steady state, whatever heat enters one end must leave the other, so $q$ is the same at every point. With $k$ and $A$ constant, $dT/dx = -q/(kA)$ is then constant too, so the temperature falls linearly from $T$ to $T_0$. That means $dT/dx = (T_0 - T)/L$, and

$$q = -kA\,\frac{T_0 - T}{L} = \frac{kA}{L}\,(T - T_0)$$

This is proportional to $\Delta T$.

The filament itself is heated along its whole length rather than at one end. With power $p$ per unit length and both ends held at $T_0$, the steady state is $kA\,d^2T/dx^2 = -p$. That gives a parabolic profile, $T(x) - T_0 = p\,x(L - x)/(2kA)$, whose mean rise is $pL^2/(12kA)$. So the total power is $P = pL = (12kA/L)\,\Delta T_{mean}$, still proportional to the temperature rise. Either way, the proportionality holds because the equations are linear as long as $k$ doesn't change over the small temperature range.

**Radiation** follows the Stefan–Boltzmann law: a surface at $T$ emits $\varepsilon\sigma A T^4$. It also absorbs from its surroundings at $T_0$, and for a small object inside a large enclosure it absorbs with the same efficiency that it emits (Kirchhoff's law), so it absorbs $\varepsilon\sigma A T_0^4$. The net loss is $\varepsilon\sigma A(T^4 - T_0^4)$. This isn't linear, but for a small rise it nearly is. Writing $T = T_0 + \Delta T$ and expanding to first order:

$$T^4 = T_0^4\left(1 + \frac{\Delta T}{T_0}\right)^4 \approx T_0^4\left(1 + \frac{4\Delta T}{T_0}\right) = T_0^4 + 4T_0^3\,\Delta T$$

That's just the derivative $d(T^4)/dT = 4T^3$. So the net loss is $\approx 4\varepsilon\sigma A T_0^3\,\Delta T$, and the first term dropped is smaller by a factor of about $1.5\,\Delta T/T_0$: under 2% for a rise of 20 K from 293 K.

Near room temperature, radiation is also orders of magnitude smaller than conduction, because tungsten's emissivity is low (a few percent) and $4\sigma T_0^3$ is only about 6 W/m²K. Either way, the total loss is $G\,\Delta T$ for some thermal conductance $G$.

(What matters is that the loss is linear in $\Delta T$, which holds when the temperature rise is small. It doesn't require radiation itself to be negligible.)

The three relations are:

- power in: $P = I^2 R$;
- power out: $P = G\,\Delta T$;
- resistance: $R = R_0(1 + \alpha\,\Delta T)$.

Eliminating $\Delta T$:

$$R = R_0\left(1 + \frac{\alpha I^2 R}{G}\right) \quad\Rightarrow\quad R = \frac{R_0}{1 - c\,I^2}, \qquad c = \frac{\alpha R_0}{G}$$

When the self-heating is small ($cI^2 \ll 1$), this is $R \approx R_0(1 + cI^2)$: a straight line in $I^2$ with intercept $R_0$ and slope $R_0 c$. The fit in 3.4 is that line.

**The linearisation's error is negligible here.** The neglected term is of order $(cI^2)^2$. For the default setpoints, fitting a straight line to the exact curve biases the intercept by:

| Resistance rise at 300 mA | Intercept bias |
| --- | --- |
| 2% | −0.008% |
| 5% | −0.05% |
| 10% | −0.19% |

At about 10 mW into a 0.1 Ω filament the rise is expected to be a few percent at most. A larger rise would show as curvature and a large $\chi^2_\nu$ (3.4.2). The equations above are exactly linear in other variables too, $1/R$ against $I^2$ or $R$ against $P = VI$, but at these heating levels the difference is negligible.

**The filament's uneven temperature doesn't break this.** Its legs run cooler than its centre, but with linear heat transport the temperature profile keeps the same shape and simply scales with the power. So $R - R_0$ is still proportional to the power to first order, with local values of $\alpha$ and $G$ folding into an effective $c$. That's why the non-uniform temperature profile, which rules out inferring temperature from resistance, doesn't affect this extrapolation.

# Status of assumptions

Confirmed:

- The DP932E has the DP900-HIRES option: 1 mA programming and 0.1 mA readback resolution, which is what `CURRENT_READBACK_RESOLUTION_AMPS` assumes. A side effect of enabling it is that `*IDN?` reports `DP932A`. The supply is a DP932E, and the DP932E's specifications are the ones that apply.
- Each `:MEASure:CURRent?` takes a new measurement, and measurements that follow each other too closely hold up setpoint changes. See "Appendix: the supply's current readback".
- A 1× probe is on the scope's channel 1. The PVP3150 has a 1×/10× switch, so the procedure still asks the operator to check it (step 1.4). A probe switched to 10× would read 10× low while the scope is set to 1×, and would add an attenuation tolerance that isn't in the budget in 3.4.
- Both instruments are within their calibration interval (scope 18 months, supply 12 months), so the data-sheet bounds used in 3.4 apply.

All SCPI commands in this document have been checked against the DP900 and DHO800/DHO900 programming guides.

The defaults are tuned for filaments with $R_0 \approx 0.1\ \Omega$ (10–30 mV over 100–300 mA). "Other filaments" below says what to change for filaments far from that.

# Implementation order

The changes split into ten commits. Each one must build, pass `cargo clippy --all-targets -- -D warnings` and `cargo fmt --check`, and run end to end with `--mock` (`1_ARCHITECTURE.md` §19).

If clippy flags something as unused before the commit that uses it, mark it `#[expect(dead_code)]` with a comment naming that commit, and remove the attribute there. `expect` rather than `allow`, so the attribute fails the build if it's forgotten.

Commits 5 and 6 don't depend on 2–4, and can be done before them.

1. **Make `Polarity` serialisable.**
   - Hoist `serde` to `[workspace.dependencies]`, add it to `host`, and derive `Serialize`/`Deserialize` on `Polarity`.
   - Update A7 and §7.2 in `1_ARCHITECTURE.md`.
   - No behaviour change.
2. **Add regulation mode and overcurrent protection to the supply.**
   - `RegulationMode` (serialisable), `get_regulation_mode`, `set_overcurrent_protection` and `get_overcurrent_tripped` in `host`, plus the `OFFMode` and OCP-clear additions to `reset`.
   - The pause between current measurements in `get_current`.
   - The matching `FilamentSystem` methods, adapters and mocks.
   - Check on the rig: with the output on into the filament, the mode reads `CC`.
3. **Read the scope from a single acquisition.**
   - The explicit `reset` settings, and `get_voltages` replacing `get_voltage` and `ClippedVoltage`.
   - `FilamentSystem::get_filament_voltages`, `FilamentSnapshot::filament_voltage: Option<f64>`, and "Clipped" in the filament block.
   - The signed mock voltage.
   - `ProcedureError::Check`, first used here: the stub `measure_at` records the average and fails with `Check` if the reading is clipped.
   - Check on the rig: the stub still measures. Temporarily setting a scale far too small shows "Clipped" in the filament block without ending the run.
4. **Add `set_vertical_scale` to `FilamentSystem`**, with its adapter (over the existing `host` method) and mock.
5. **Switch the Python scripts to JSON on stdin**, with shared schemas (see "`python/`" below).
   - `schemars` as a workspace dependency, derived alongside `serde` wherever a type crosses the boundary (including `Polarity` in `host` and `Measurement`).
   - `jsonschema` in `requirements.txt`.
   - `run_script` writes a serialisable input to stdin.
   - The input and output types for `mean_and_standard_error.py`, the schema snapshot test, the generated `python/schemas/`, and `python/script_io.py`.
   - `mean_and_standard_error.py` reads `{"samples": [...]}`.
   - Update `1_ARCHITECTURE.md` §4 (layout) and §12.
   - Check: the stub still records measurements, under `--mock` and on the rig.
6. **Add the analysis scripts.**
   - `numpy` and `scipy` in `requirements.txt`, and the extended `check_environment`.
   - The input types (in `python.rs`), and the output and parameter types (`Derived`, `ColdResistancePointAnalysis`, `ColdResistanceAnalysis` and `ColdResistanceFitParameters` in `results.rs`), for both scripts, with their wrappers and regenerated schemas.
   - `cold_resistance_point.py`, `cold_resistance_fit.py` and `test_cold_resistance.py`.
   - A `python` job in `.github/workflows/ci.yml`, added here rather than earlier because `python -m unittest` fails when there are no tests. It sets up Python 3.14 (the venv's version) with `actions/setup-python@v7`, runs `pip install -r requirements.txt`, and runs `python -m unittest`, all in `filament-characterisation/characteriser/python`.
   - Done when `python -m unittest` and the schema test pass.
7. **Lay the procedure's groundwork.**
   - The `constants.rs` changes.
   - `prepare`: the probe and warm-up confirmations, and the removal of the 30 V limit.
   - `pump_down`'s wait for `FILAMENT_OPERATING_PRESSURE_MBAR`.
   - The helpers `check_conditions`, `ramp_to`, `change_polarity`, `take_samples` and `wait_for_settle`, and the procedure constants.
   - Rewrite the stub `measure_cold_resistance` to use the helpers at a single current (still recording into the old `cold_*` fields), so they're exercised on the rig before the real procedure exists. Set the cold-resistance voltage limit and OCP at its start.
   - Include the Rust tests for `ramp_to` and `change_polarity`.
8. **Measure the setpoints.**
   - In `results.rs`: `ColdResistance` (with `analysis` still `None`) and `ColdResistancePoint`, replacing the four `cold_*` fields.
   - The room- and chamber-temperature prompts in 3.0, the effective bounds, and the end chamber-temperature prompt in 3.2.
   - Sections 3.0–3.2 and the per-point analysis (3.3).
   - Check on the rig: a full run records nine points, each with a resistance.
9. **Fit and report.**
   - 3.4 (including the correction to 20 °C, 3.4.7) and 3.5.
   - The `--mock` Rust test for $R_0 = 0.096$ Ω.
10. **Tidy up.**
    - Remove anything the stub left behind that's now unused.
    - Make sure every `expect(dead_code)` is gone.
    - Check the acceptance criteria.

# Changes outside the procedure

## `constants.rs`

- Raise `MAXIMUM_HEATING_CURRENT_AMPS` to 0.3, the largest cold-resistance setpoint. `set_heating_current_limit` refuses anything above it, and 300 mA dissipates only about 10 mW in a 0.1 Ω filament.
- Fix the doc comment on `MAXIMUM_HEATING_VOLTAGE_VOLTS`: the DP932E's channels 1 and 2 go to 30 V, not 32 V (32 V is the DP932A/U). The constant stays as a general ceiling. The cold-resistance measurement sets its own, much lower, limit (see below).
- Add `FILAMENT_OPERATING_PRESSURE_MBAR = 1e-5`. This is the pressure the chamber must reach before any current flows, and it resolves the `TODO` in `pump_down`. It's an arbitrary but comfortable threshold.
- Add `FILAMENT_ABORT_PRESSURE_MBAR = 5e-5`. If the pressure rises above this while the filament is powered, the procedure stops.

## `host::power_supply::PowerSupply`

The commands below are confirmed against the DP900 programming guide; section numbers refer to it. The existing methods' commands are also confirmed as they are: `:MEASure:CURRent? CH1` (4.6.2, returning e.g. `0.0500`, four decimals to match the 0.1 mA HIRES resolution), `:OUTPut CH1,<0|1>` and `:OUTPut? CH1` (4.8.16), and `:SOURce1:CURRent` / `:SOURce1:VOLTage` (4.9.1, 4.9.7).

Add these methods, following the existing style (lock the state, one USBTMC transaction, parse):

- **`get_regulation_mode() -> Result<RegulationMode, _>`**, with a new `RegulationMode { ConstantCurrent, ConstantVoltage, Unregulated }` enum beside `Polarity`. Use `:OUTPut:MODE? CH1` (4.8.2), which returns `CV`, `CC` or `UR`. `:OUTPut:CVCC? CH1` (4.8.1) is documented identically.
- **`set_overcurrent_protection(current: f64) -> Result<(), _>`**. It sends three commands:
  1. `:OUTPut:OCP:VALue CH1,<amps>` (4.8.8) sets the level.
  2. `:OUTPut:OCP:DELay CH1,10` (4.8.6) sets the delay. This is how long OCP is ignored after the output changes, so it covers a turn-on overshoot when `change_polarity` re-enables the output at a setpoint. 10 ms is the default, but set it explicitly rather than inheriting whatever it was left at.
  3. `:OUTPut:OCP CH1,ON` (4.8.7) enables it.

  When OCP trips, the supply disables the output itself.

- **`get_overcurrent_tripped() -> Result<bool, _>`**: `:OUTPut:OCP:QUES? CH1` (4.8.4). It returns `1` or `0` (an example in the guide shows `YES`/`NO`, but testing confirmed `1`/`0`), so error on anything else.

Extend `reset` to put two more things into a known state before anything else. Both go first, before the output is disabled:

1. **`:OUTPut:OFFMode 0V` (4.8.9).** This is a global setting, not per channel. It makes a disabled output actively hold 0 V, so by the time `set_polarity` switches the relays the output really is at 0 V. The alternatives don't guarantee that. `DELAYOFF` turns the output off after a delay, so the relays could switch while it was still live. `IMMEOFF` doesn't guarantee its fall time. 0V is the default, but it persists, so set it explicitly.
2. **`:OUTPut:OCP:CLEar CH1` (4.8.5)**, which clears any OCP event left latched from a previous run.

Make **`get_current`** pause between measurements. Each `:MEASure:CURRent?` takes a new measurement of about 180 ms, and measurements that follow each other too closely stop the supply applying setpoint changes (see "Appendix: the supply's current readback").

- Keep the `Instant` the last measurement's reply arrived in the supply's state.
- Before each query, while holding the lock, sleep until `MEASUREMENT_PAUSE` has passed since then. `MEASUREMENT_PAUSE` is 200 ms, a constant in `power_supply.rs`.
- Enforcing the pause in `host` means it covers every caller: the procedure's samples and the snapshot poll, which would otherwise interleave their measurements.
- Setpoint writes are unaffected, apart from waiting for the lock. In the tests, with this pause, a setpoint written just before a measurement always showed in the measurement after it, about 0.6 s later.

Add `serde` (with `derive`) to `host`, hoisted to `[workspace.dependencies]` as in `1_ARCHITECTURE.md` §4.1, and derive `Serialize` and `Deserialize` on `Polarity` and `RegulationMode` so `results.rs` can store them directly. This supersedes assumption A7; update A7 and §7.2 in `1_ARCHITECTURE.md` to say so.

## `host::oscilloscope::Oscilloscope`

The commands below are confirmed against the DHO800/DHO900 programming guide; section numbers refer to it. The existing methods' commands are also right as they are: `:STOP`, `:RUN`, `:CLEar`, `:MEASure:CLEar`, `:CHANnel<n>:DISPlay`, `:CHANnel1:OFFSet`, `:CHANnel1:SCALe` and `:TIMebase:SCALe`. `:CHANnel1:SCALe?` returns scientific notation (e.g. `1.000000E-01`), so `set_vertical_scale`'s read-back comparison parses correctly.

- **Make `reset` explicit about everything the measurement depends on**, since none of it may be left to however the scope was last used:
  - DC coupling (`:CHANnel1:COUPling DC`, 3.6.2).
  - Probe ratio 1× (`:CHANnel1:PROBe 1`, 3.6.8). Set it before the vertical scale, because the probe ratio changes the scale's valid range.
  - 20 MHz bandwidth limit (`:CHANnel1:BWLimit 20M`, 3.6.1). This is the only limit the DHO800 offers; the alternative is `OFF`, i.e. full bandwidth. The signal is DC, so everything above it is noise, and the high-frequency part inflates VMAX and VMIN, which would push the scale search to a coarser scale than the signal needs.
  - Normal acquisition mode (`:ACQuire:TYPE NORMal`, 3.3.3). Not `AVERages` (which averages whole waveforms across acquisitions, so consecutive samples wouldn't be independent) or `PEAK` (which exaggerates noise).
  - Auto trigger sweep (`:TRIGger:SWEep AUTO`, 3.27.4). This makes the scope acquire even when nothing triggers it, so the display shows a live trace before the first measurement. A DC signal never crosses the trigger level, so in normal sweep the screen would sit waiting. The first `get_voltages` call switches the sweep to single, because `:SINGle` is equivalent to `:TRIGger:SWEep SINGle` (3.1.4), and it stays there.
  - Measurements over the main time base (`:MEASure:AREA MAIN`, 3.17.19), not a zoom window.
  - VAVG, VMAX and VMIN measurement items on channel 1, added with the command form (`:MEASure:ITEM VAVG,CHANnel1` etc., 3.17.2) as `get_voltage` already does for VAVG.

  The existing 2 ms/div timebase stays: 10 div × 2 ms = 20 ms is exactly one 50 Hz mains cycle, so each VAVG averages out mains pickup and the supply's 100 Hz rectifier ripple.

- **Replace `get_voltage` with `get_voltages() -> Result<Voltages, OscilloscopeError>`**, where `Voltages { average, maximum, minimum }` holds each value as an `Option<f64>`. `None` means the scope still reported its invalid value (9.9E37) after the existing retries. Remove `OscilloscopeError::ClippedVoltage`. Because `reset` now adds all three measurement items, `get_voltages` doesn't add any: remove the lazy `:MEASure:ITEM VAVG,CHANnel1` from the old `get_voltage`, and the `is_measuring_voltage` flag in the oscilloscope's state that tracked it. The average alone can't detect clipping: it stays defined while the peaks are clipped, and is then biased, because the clipped samples are pinned at the edge of the range. While holding the lock:
  1. Arm a single acquisition (`:SINGle`, 3.1.4).
  2. Poll `:TRIGger:STATus?` (3.27.3), which returns `TD`, `WAIT`, `RUN`, `AUTO` or `STOP`, sleeping 50 ms between queries:
     - On `WAIT`, the scope is armed and waiting. Send `:TFORce` (3.1.5) once, since a DC signal may never cross the trigger level. The guide says `:TFORce` works in single mode.
     - On `STOP`, once the scope has reported any other status first, the acquisition is complete. Noise crossing the trigger level can trigger it before the force is sent; that's fine, because it's still an acquisition that began after the arm.
     - A `STOP` before any other status is the previous acquisition's, so keep polling. The scope sometimes answers the first query, about 30 ms after `:SINGle`, before processing it, and it occasionally (about 3% of acquisitions on the rig) ignores `:SINGle` altogether. Taking that `STOP` as complete reads the previous acquisition's measurements again, silently duplicating a sample, or, once the screen has cleared, invalid values that look like clipping. And because `WAIT` is never seen, the force is never sent.
     - If the scope is still stopped 300 ms after `:SINGle`, it ignored it, so send `:SINGle` again. It reports no error (`:SYSTem:ERRor?` gives `0,"No error"`), so there's no telling why. One re-send has always been enough on the rig. A normal arm reports `WAIT` within about 25–110 ms, and the slowest seen within about 150 ms.
     - Anything else, keep polling.
     - If `STOP` doesn't arrive within `ACQUISITION_TIMEOUT` (2 s, a constant in `oscilloscope.rs`; an acquisition has been seen to take ~360 ms), return an error. Waiting for `WAIT` before forcing avoids sending the force before the scope has filled its pre-trigger buffer and armed, when it might be ignored and leave the scope waiting forever.
  3. Query `:MEASure:ITEM? VAVG,CHANnel1`, then `VMAX` and `VMIN`, each with the existing retry-on-9.9E37 logic. The scope is stopped, so all three come from the same acquisition. The guide doesn't give the invalid value itself; it only says that results out of the valid range are invalid. 9.9E37 is what your existing code has observed, and that's what `CLIPPED_VOLTAGE` encodes.

  Taking a single acquisition, rather than querying a running scope at least 20 ms apart, guarantees three things:
  - **All three values come from the same acquisition.** On a running scope, three separate queries can straddle two acquisitions.
  - **The acquisition started after the call,** so it reflects the state after the last change of current, polarity or scale. A running scope can return a value from an acquisition that began before the change.
  - **Samples are independent however fast the scope's measurement engine updates.** A running scope's cycle is the 20 ms window plus dead time and measurement processing, and that total isn't specified, so a 20 ms spacing doesn't guarantee a new value.

  The snapshot poll uses the same method, which is fine: the lock makes the whole sequence atomic. The scope is left stopped between samples, which only means the display updates once per sample.

## `hardware` module

- **Stop treating a clipped voltage as a hardware failure.** At the moment `RealFilamentSystem::snapshot` propagates `OscilloscopeError::ClippedVoltage`. Three consecutive clipped polls would then end the run as `HardwareFailed` (§8.1), and the vertical-scale search in 3.1 deliberately produces clipped readings. Change `FilamentSnapshot::filament_voltage` to `Option<f64>`, matching `Voltages`. It's the average, or `None` if _any_ of the average, maximum and minimum is `None`, because an average with clipped peaks is biased and shouldn't be displayed as if it were good. Say so in its doc comment, since that's a slightly wider meaning of `None` than on `Voltages`. The headroom check belongs to the procedure, not the snapshot. Render `None` as "Clipped" in the filament block. A clipped reading is still a real reading (§7.1), just not a number.
- Replace `get_filament_voltage` with `get_filament_voltages() -> Result<Voltages, HardwareError>`, returning `host`'s `Voltages` directly. Like `Polarity`, it's plain data rather than an instrument type, so it's an exception to the §7.5 rule that nothing outside `real.rs` names a `host` type; note that in §7.5.
- Extend `FilamentSystem` with:
  - `get_regulation_mode() -> Result<RegulationMode, HardwareError>`;
  - `get_overcurrent_tripped() -> Result<bool, HardwareError>`;
  - `set_overcurrent_protection(current: f64) -> Result<(), HardwareError>`;
  - `set_vertical_scale(scale: f64) -> Result<(), HardwareError>`, in volts per division;
- **Mocks** (§7.6). For `--mock` to get through the procedure's checks, the mock's filament voltage must be `MOCK_FILAMENT_RESISTANCE_OHMS` (0.096) × the set current × +1 for `Forward` / −1 for `Reverse`, or 0 V with the output off or `Nil`. The average, maximum and minimum are all that value. The mock current readback returns the set current, the regulation mode is always `ConstantCurrent`, and OCP never trips. This is still a contract rather than a simulation: no noise, no time dependence, no heating.

## `procedure` module

Add `ProcedureError::Check(String)` for the procedure's own checks, as §11.1 anticipates: clipping after the scale is chosen, leaving constant-current mode, an OCP trip, a pressure excursion, or a failed polarity sanity check. Log with `error!` before returning it, as usual.
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

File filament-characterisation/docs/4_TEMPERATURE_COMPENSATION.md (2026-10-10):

# Compensating for the filament mount's temperature

This document specifies how the cold-resistance measurement (`2_COLD_RESISTANCE.md`) compensates for the filament's mount warming during a run. It adds reference measurements at a fixed current through the run, and the fit uses them to remove the mount's drift from every other measurement before fitting $R$ against $I^2$.

Everything in `1_ARCHITECTURE.md` and `2_COLD_RESISTANCE.md` still applies unless this document says otherwise.

## Why

### The problem

Three cold-resistance runs on the same filament gave $\chi^2_\nu$ of 75, 63 and 65, where about 1 is expected. The residuals look random when sorted by current. In measurement order, though, they follow a common pattern: the first point is 8–17σ low, and the rest rise through the run.

The third run measured its first setpoint again at the end, and the resistance had risen by 362 µΩ (+0.37%).

### The cause

The filament's own power warms its legs and mount, which in vacuum can only lose heat slowly by conduction to the flange. As the mount warms, the whole filament's temperature profile shifts up, and every reading rises with it. The setpoints are measured in random order, so this rise over time appears as scatter about the fitted line rather than as a bias in its slope.

A 30-minute hold test (`host/src/bin/hold.rs`) confirmed it:

| Hold | Change in R | Time constant τ |
| --- | --- | --- |
| 300 mA for 15 min | +942 µΩ (+0.94%) | 153 s |
| Then 100 mA for 15 min | −851 µΩ (−0.83%) | 160 s |

These come from fitting a single exponential to each hold.

- **It's thermal.** The change reverses with the power, which instrument drift wouldn't do.
- **It's not the chamber.** The second and third runs drifted about equally, though the chamber warmed 0.3 K in one and 2.0 K in the other.
- **There's probably a second, slower component,** with a time constant of tens of minutes. R was still moving at the end of both holds. Adding a linear term to the fit gives 9–17 µΩ/min of slow drift, and moves the fast time constant to anywhere from 95 to 190 s, so τ is only known roughly.

### What this changes

- **R₀:** the drift moves it by about 0.1–0.4 mΩ (0.1–0.4%). That's small next to its ±2.5 mΩ uncertainty, which the supply's readback offset dominates.
- **The slope b:** it varies about ±6% between runs because of the drift.
- **χ²_ν:** it's large in every run, so the poor-fit warning fires every time and stops meaning anything.
- **Later work:** once the readback offset is calibrated, and for the heating characterisation, the drift becomes one of the largest errors.

### The approach

Resting between setpoints was rejected: with τ ≈ 155 s, letting the mount cool fully would add 1.5–2 hours to a run. Warming up first was rejected because it biases R₀ high by the equilibrium warming. A physical thermal model was rejected for now, because it depends on a model being right (see "Alternatives considered").

Instead, **reference measurements at a fixed current**:
- one at the start, while the mount is still cold;
- more through the run, and one at the end.

Comparing the reference readings with the first gives the mount's drift over time. Interpolating between them gives the drift at the moment each setpoint was measured, which is then subtracted from that setpoint before fitting. This makes no assumption about the drift's shape. R₀ then describes the filament with its mount at the start temperature.

## The correction

### Why the same amount is subtracted at every current

Near room temperature, tungsten's resistivity is $\rho(T) = \rho_0[1 + \alpha(T - T_0)]$. A rise of $\Delta T$ adds a fixed amount, $\rho_0\alpha\,\Delta T$, however warm the filament already is.

A warming mount raises the filament's whole temperature profile, legs and centre alike, by its own $\Delta T$. That follows from the linearity of heat transport, the same argument as in `2_COLD_RESISTANCE.md`'s opening section. So for a filament of cross-section $A$:

$$R' = \frac{1}{A}\int \left[\rho(T(x)) + \rho_0\alpha\,\Delta T\right] dx = R + R_0\,\alpha\,\Delta T$$

The resistance rises by the same number of ohms at every current. A reference current repeated over time therefore measures exactly the amount to subtract from every other setpoint measured at the same moment:

$$\Delta R(t) = R_{ref}(t) - R_{ref}(t_0)$$

The self-heating at the reference current is the same every time it's measured: same current, same settling. So it cancels in that difference.

**What's ignored:**
- α's variation over a few kelvin;
- thermal expansion, which changes resistance about 1,000 times less than α does;
- the second-order effect of a slightly warmer filament dissipating slightly more power.

### Interpolating the drift

References are measured at times $t_0 < t_1 < \dots < t_m$. A setpoint measured at time $t_i$, between references $j$ and $j+1$, gets the drift interpolated linearly between them:

$$w_i = \frac{t_i - t_j}{t_{j+1} - t_j}, \qquad \Delta R(t_i) = (1 - w_i)\,R_{ref,j} + w_i\,R_{ref,j+1} - R_{ref,0}$$

and its corrected resistance is

$$R'_i = R_i - \Delta R(t_i) = R_i - (1 - w_i)\,R_{ref,j} - w_i\,R_{ref,j+1} + R_{ref,0}$$

- **Linear interpolation** is used because it assumes nothing about the drift's shape and can't overshoot between references.
- **Every setpoint has a reference before and after it,** because references are measured first and last (see "The schedule"). A point outside the references' time range is an error, not something to extrapolate.
- **The time of a setpoint, $t_i$,** is the mean of the midpoints of its two polarities' sampling windows. If the positive polarity's samples are taken from $t^+_{start}$ to $t^+_{end}$, and the negative polarity's from $t^-_{start}$ to $t^-_{end}$:

  $$t_i = \frac12\left(\frac{t^+_{start} + t^+_{end}}{2} + \frac{t^-_{start} + t^-_{end}}{2}\right) = \frac{t^+_{start} + t^+_{end} + t^-_{start} + t^-_{end}}{4}$$

  A point's $R$ weights the two polarities equally, so for a drift that's linear over the point, this time is exact. A reference's time is calculated the same way.

### Interpolation error

The interpolated $\Delta R(t_i)$ is only an estimate of the drift at $t_i$. It's a straight line between the references, but the true drift, $f(t)$, curves: it rises quickly at first, then levels off. So each subtraction is slightly wrong, by more where the drift curves sharply or the references are far apart.

That error is part of each corrected point's uncertainty. It's estimated as $u_{interp,i}$ below, and added in quadrature to $u^2(R'_i)$, the diagonal of the covariance matrix the fit uses (see "Propagating the uncertainty"). Without it, the fit would treat the correction as exact, and the leftover curvature would show up as excess χ².

For a linear interpolant, the error's size is $\tfrac12 |f''(\xi)|(t - t_j)(t_{j+1} - t)$ for some $\xi$ in the interval. It's zero at the references and largest midway between them.

- **Estimating the curvature:** $f''$ is estimated from each interval's neighbouring references, using the second divided difference of three consecutive references:

  $$f'' \approx 2\left[\frac{R_{ref,k+1} - R_{ref,k}}{t_{k+1} - t_k} - \frac{R_{ref,k} - R_{ref,k-1}}{t_k - t_{k-1}}\right] \Big/ (t_{k+1} - t_{k-1})$$

  Each interval uses the larger magnitude of the estimates centred on its two ends.
- **The first interval:** the first reference has no estimate centred on it, because no reference comes before it. That's where the drift curves most, so the next estimate alone would understate it. Instead, its estimate is extrapolated back from the two estimates centred on references 1 and 2, $c_1$ and $c_2$, assuming the curvature shrinks geometrically, as an exponential approach's does:

  $$c_0 = \max\left(c_1,\; c_1\left(\frac{c_1}{c_2}\right)^{(t_1 - t_0)/(t_2 - t_1)}\right)$$

  **Where the extrapolation comes from.** Here $c_k$ is the estimate centred on reference $k$, roughly the average of $|f''|$ from $t_{k-1}$ to $t_{k+1}$. For an exponential approach, $f(t) = a - b\,e^{-t/\tau}$, so

  $$f''(t) = -\frac{b}{\tau^2}e^{-t/\tau}, \qquad |f''(t)| = \frac{b}{\tau^2}e^{-t/\tau}$$

  The curvature at a time $\Delta$ later, relative to that at $t$, is

  $$\frac{|f''(t + \Delta)|}{|f''(t)|} = e^{-\Delta/\tau}$$

  That doesn't depend on $t$: the curvature shrinks by the same factor over any stretch of length $\Delta$, wherever it is in the run. Taking each ratio as later over earlier:

  - $c_2$ is $t_2 - t_1$ after $c_1$, so $c_2/c_1 = e^{-(t_2 - t_1)/\tau}$, and so $c_1/c_2 = e^{(t_2 - t_1)/\tau}$.
  - $c_1$ is $t_1 - t_0$ after $c_0$, so $c_1/c_0 = e^{-(t_1 - t_0)/\tau}$, and so $c_0 = c_1\,e^{(t_1 - t_0)/\tau}$.

  τ isn't known. But writing the second exponent as a fraction of the first,

  $$e^{(t_1 - t_0)/\tau} = \left(e^{(t_2 - t_1)/\tau}\right)^{(t_1 - t_0)/(t_2 - t_1)} = \left(\frac{c_1}{c_2}\right)^{(t_1 - t_0)/(t_2 - t_1)}$$

  gives $c_0 = c_1\,(c_1/c_2)^{(t_1 - t_0)/(t_2 - t_1)}$, without τ. The drift levels off, so $c_1 > c_2$, and the extrapolated $c_0$ is larger than $c_1$, as the curvature at the start should be. With the schedule's spacing, about 80 s then 120 s, the measured ratio is raised to the power ⅔.

  Treating each $c_k$, which is an average over a span, as the curvature at $t_k$ is an approximation, and the hold test's slower second component isn't a single exponential. The test against exponential drifts across a range of time constants (test 3) is what shows it works.

  With 400 µΩ of drift, this bounds the first interval's actual error for time constants from 60 to 250 s, e.g. 11.8 µΩ against an actual 10.3 µΩ at 155 s. The estimate centred on reference 1 alone gives 7.5 µΩ. It needs four references and a nonzero $c_2$, and otherwise falls back to $c_1$.
- **The last interval** has no estimate centred on the last reference either. But the drift has levelled off by then, so the one centred on the reference before is enough.
- **As an uncertainty:** the resulting bound $e_i = \tfrac12|f''|(t_i - t_j)(t_{j+1} - t_i)$ is treated as rectangular, so $u_{interp,i} = e_i/\sqrt3$. It's independent between points.
- **It's conservative.** Noise in the references inflates the second differences, and each interval takes the larger of two estimates. Noise can only make the first interval's extrapolation larger, because it's never less than $c_1$.
- **The size:** with τ ≈ 155 s, a run's drift amplitude of about 0.5 mΩ, and references about 120 s apart, the largest interpolation error is about 40 µΩ at the start of the run, where the drift curves most, falling as it levels off. That's comparable to a point's own uncertainty, which is why the schedule puts an extra reference early.

### Propagating the uncertainty

The corrected resistances are no longer independent:
- every one includes $+R_{ref,0}$;
- neighbouring points share their bracketing references.

So the fit uses their full covariance matrix, not just their individual uncertainties.

- **In the fit script,** every input is a `ufloat` from the `uncertainties` package: each point's $V$ and $I$, and each reference's $V$ and $I$, as in 3.3. The correction is computed with them, so the package tracks every correlation.
- **The covariance matrix** of the corrected $R'_i$ is `uncertainties.covariance_matrix(...)`, with $u_{interp,i}^2$ added to its diagonal.
- **The fit** is the same weighted least squares as 3.4.1, with that matrix as `sigma`. `curve_fit` takes a 2-D `sigma` as the data's covariance and does generalised least squares, with `absolute_sigma=True` as before. Its `info["fvec"]` is then the whitened residuals, so χ² is still `np.sum(info["fvec"] ** 2)` and 3.4.2 is unchanged.

**Example.** A point midway between references $j = 0$ and $1$ ($w = \tfrac12$) has $R' = R_i - \tfrac12 R_{ref,1} + \tfrac12 R_{ref,0}$. So

$$u^2(R') = u_i^2 + \tfrac14 u_{ref,1}^2 + \tfrac14 u_{ref,0}^2 + u_{interp,i}^2$$

With the typical 15–30 µΩ, a point's uncertainty grows by roughly a third. The fit's statistical uncertainty in R₀ also gains the first reference's uncertainty, since every corrected point includes $R_{ref,0}$. The covariance matrix accounts for all of that.

### The corner analysis

The readback-offset corner analysis (3.4.5) recomputes every resistance with currents shifted by $\pm\delta_{max}$. The references' resistances depend on the offset too, so they're recomputed with the same shift, and the correction applied afresh, before each corner's refit. That's why the fit receives the references' $V$ and $I$, not just their resistances.
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

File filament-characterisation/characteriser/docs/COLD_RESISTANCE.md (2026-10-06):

# Cold resistance calculation steps

This document specifies the real body of `measure_cold_resistance` in `filament-characterisation/characteriser`, plus the changes it needs elsewhere in the crate and in `host`. It builds on `docs/ARCHITECTURE.md`. Everything there still applies unless this document says otherwise: code style (§18), doc comments, saving after every measurement (§10.3), safe shutdown (§16), and "no statistics in Rust" (§2).
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

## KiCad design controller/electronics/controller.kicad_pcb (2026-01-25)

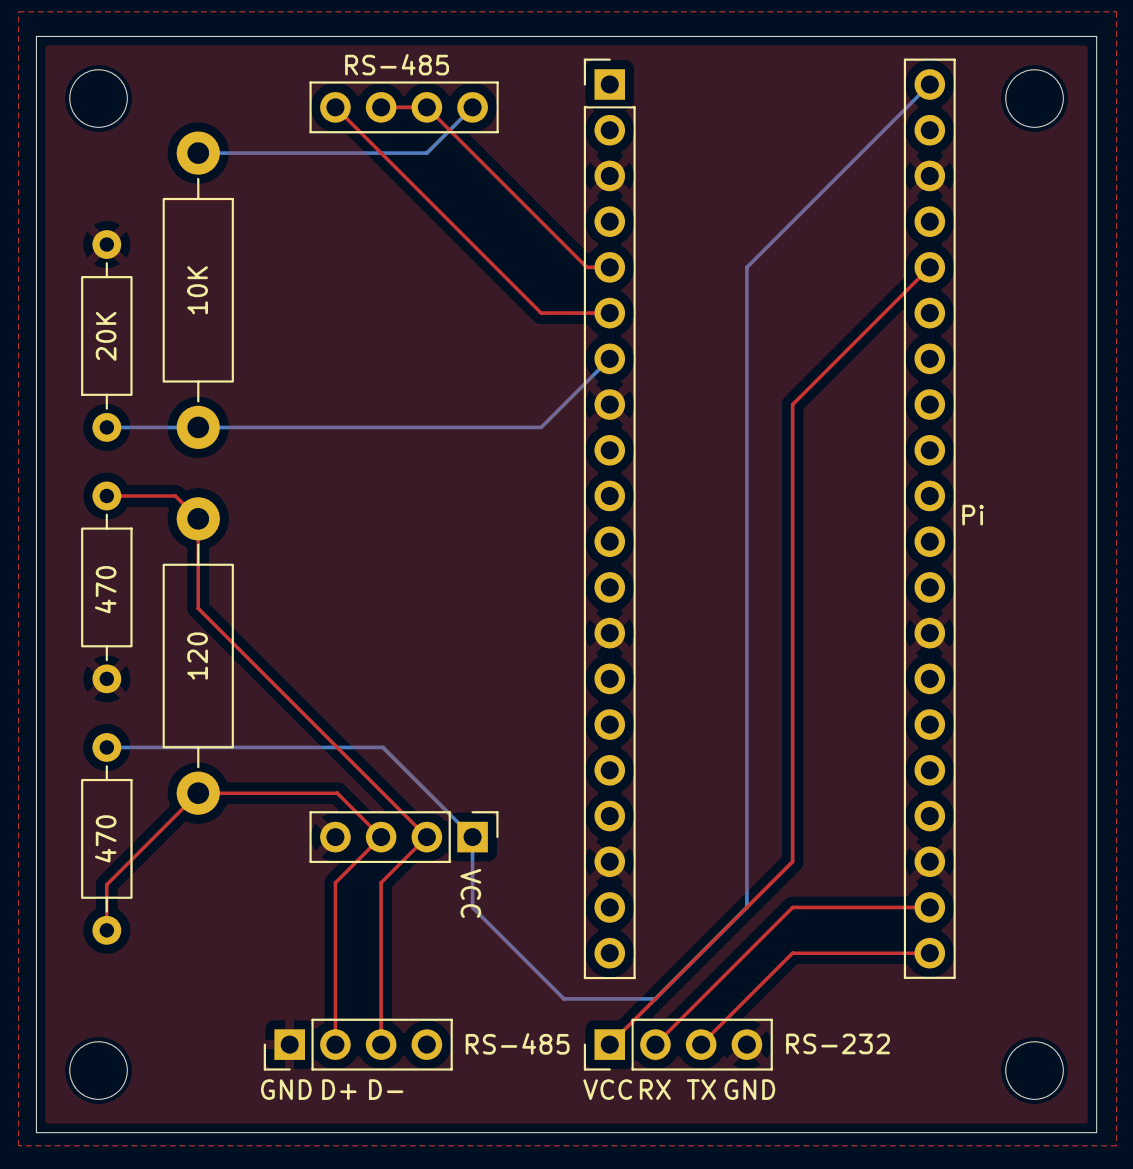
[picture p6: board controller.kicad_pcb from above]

Board: 2 copper layers, 58.9 x 60.9 mm, 9 parts (0 on the bottom side), 11 nets.

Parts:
10K: 10k; R_Axial_DIN0411_L9.9mm_D3.6mm_P15.24mm_Horizontal
20K: 20k; R_Axial_DIN0207_L6.3mm_D2.5mm_P10.16mm_Horizontal
120: 120; R_Axial_DIN0411_L9.9mm_D3.6mm_P15.24mm_Horizontal
470, 470#2: 470; R_Axial_DIN0207_L6.3mm_D2.5mm_P10.16mm_Horizontal
Pi: Raspberry Pi Pico 2; Raspberry_Pi_Pico_2_male_headers
RS-232: UART to RS-232 converter; PinHeader_1x04_P2.54mm_Vertical
RS-485: RJ45 Jack; PinHeader_1x04_P2.54mm_Vertical
RS-485#2: UART to RS-485 converter; UART_to_RS_485_converter

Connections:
+3.3V: Pi.36 (3V3), RS-232.1 (VCC)
+5V: 470.1, Pi.40 (VBUS), RS-485#2.1 (VCC)
GND: 20K.2, 470#2.2, Pi.3 (GND), Pi.8 (GND), Pi.13 (GND), Pi.18 (GND), Pi.23 (GND), Pi.28 (GND), Pi.38 (GND), RS-232.4 (GND), RS-485.1 (GND), RS-485#2.4 (GND)
unnamed: Pi.5 (GPIO3), RS-485#2.6 (RE), RS-485#2.7 (DE)
unnamed: Pi.6 (GPIO4), RS-485#2.8 (DI)
unnamed: 10K.2, 20K.1, Pi.7 (GPIO5)
unnamed: Pi.21 (GPIO16), RS-232.3 (TXD)
unnamed: Pi.22 (GPIO17), RS-232.2 (RXD)
unnamed: 120.1, 470.2, RS-485.2 (D+), RS-485#2.3 (A)
unnamed: 120.2, 470#2.1, RS-485.3 (D-), RS-485#2.2 (B)
unnamed: 10K.1, RS-485#2.5 (RO)

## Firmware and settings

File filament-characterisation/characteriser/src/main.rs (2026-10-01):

mod app;
mod constants;
mod hardware;
mod procedure;
mod python;
mod results;
mod steps;
mod style;
mod ui;

use app::{App, AppEvent, Shutdown};
use clap::Parser;
use env_logger::{Builder, Target};
use futures::FutureExt;
use hardware::{
    Hardware, HardwareError, MockFilamentSystem, MockVacuumSystem, RealFilamentSystem,
    RealVacuumSystem,
};
use host::controller::Controller;
use log::*;
use procedure::Context;
use results::Characterisation;
use std::{
    any::Any,
    fs,
    io::Write,
    panic::AssertUnwindSafe,
    process::ExitCode,
    sync::{Arc, Mutex},
    time::Duration,
};
use steps::Section;
use tokio::sync::{mpsc, watch};
use tokio_util::sync::CancellationToken;

type AnyError = Box<dyn std::error::Error>;

/// How long cleaning up may take before it's given up on.
///
/// Three commands to instruments that each answer in well under a second. It's
/// bounded so that a hung instrument can't stop the terminal being restored.
const CLEANUP_TIMEOUT: Duration = Duration::from_secs(5);

/// How long the procedure is given to stop once it's been cancelled, before
/// it's aborted.
const SHUTDOWN_TIMEOUT: Duration = Duration::from_secs(2);

/// How many messages the application's event channel can hold.
///
/// There are two senders, each sending once as it finishes, so this only has to
/// be more than that.
const EVENT_CHANNEL_CAPACITY: usize = 8;

/// Reports `run`'s result and turns it into an exit status.
///
/// `main` doesn't return the `Result` itself because Rust would then report it
/// with `Debug`, which for these errors drops the `Display` message — and the
/// `Display` of a `PythonError::Environment` is what tells the operator which
/// commands to run.
#[tokio::main(flavor = "current_thread")]
async fn main() -> ExitCode {
    match run().await {
        Ok(()) => ExitCode::SUCCESS,
        Err(e) => {
            report_error(format_args!("error: {}", e));
            ExitCode::FAILURE
        }
    }
}

/// Runs the application.
async fn run() -> Result<(), AnyError> {
    init_logging()?;

    let args = Arguments::parse();

    // Check the Python environment before taking over the terminal, so the
    // operator sees the error and how to fix it.
    python::check_environment().await?;

    let hardware = build_hardware(&args).await?;

    // `ratatui::init` installs a panic hook that restores the terminal before
    // chaining to the previous hook, so a panic message isn't swallowed by the
    // alternate screen. Anything that wants to run before that restore has to
    // install its own hook *before* this call.
    //
    // Note that a panic hook can't run the asynchronous cleanup that puts the
    // filament system into a safe state — hooks are synchronous. That's why the
    // procedure task must never panic, and why every fallible call inside it
    // returns an error instead.
    let mut terminal = ratatui::init();

    // Cancelled as the first step of shutdown, which unblocks whatever the
    // procedure is waiting on.
    let cancel = CancellationToken::new();

    // The step tree. It's shared with the procedure, which mutates it, and the
    // application, which renders it. The lock is a `std::sync::Mutex` because
    // every critical section is a short synchronous mutation or one render
    // pass, and it's never held across an `.await`.
    let root = Arc::new(Mutex::new(Section::default()));

    let characterisation = Characterisation::new(!args.no_vacuum);
    if args.no_vacuum {
        info!("Running without vacuum");
    }
    let results_path = characterisation.path();
    info!("Writing results to {}", results_path.display());

    let (snapshots_tx, snapshots_rx) = watch::channel(None);
    let (events_tx, events_rx) = mpsc::channel(EVENT_CHANNEL_CAPACITY);

    // The procedure waits for the first snapshot before doing anything, so
    // nothing runs against instruments that haven't answered yet. Its result is
    // forwarded to the application; an error sending means it has already
    // gone.
    //
    // A panic is caught and forwarded too. Otherwise the task would die
    // silently and the application would wait for an event that never came.
    let ctx = Context::new(
        cancel.clone(),
        characterisation,
        Arc::clone(&root),
        snapshots_rx.clone(),
    );
    let mut procedure_task = tokio::spawn({
        let events_tx = events_tx.clone();
        let hardware = hardware.clone();
        async move {
            let event = match AssertUnwindSafe(procedure::run(ctx, hardware))
                .catch_unwind()
                .await
            {
                Ok(result) => AppEvent::ProcedureFinished(result),
                Err(panic) => AppEvent::ProcedurePanicked(panic_message(panic.as_ref())),
            };
            let _ = events_tx.send(event).await;
        }
    });

    // The poll task returns only once the hardware has failed for good, which
    // is fatal, so it's forwarded to the application to end the run. An error
    // sending means the application has already gone.
    //
    // It's left running through shutdown. It only reads, and the instruments'
    // locks keep its reads apart from the cleanup's commands.
    tokio::spawn({
        let hardware = hardware.clone();
        async move {
            let e = hardware::poll(hardware, &snapshots_tx).await;
            let _ = events_tx.send(AppEvent::HardwareFailed(e)).await;

            // Only now close the channel. The procedure sees it close as a
            // cancelled wait and reports that too, and reported first it would
            // hide the real cause behind "cancelled".
            drop(snapshots_tx);
        }
    });

    let mut app = App::new(root);
    let result = app.run(&mut terminal, snapshots_rx, events_rx).await;
    match &result {
        Ok(shutdown) => info!("Shutting down: {:?}", shutdown),
        Err(e) => error!("the application failed: {}", e),
    }

    // Everything from here runs however the loop ended, including when `run`
    // itself failed, which is why it's here rather than in the loop. The order
    // matters: the filament is made safe before anything waits on the
    // operator.

    // 1. Cancel, which unblocks whatever the procedure is waiting on.
    cancel.cancel();

    // 2. Wait for the procedure to stop. Cancelling only stops it at its next
    //    cancellation-aware await, and a plain hardware call on the way there,
    //    such as enabling the output, would race the cleanup. Waiting means the
    //    cleanup has the last word. It also lets the procedure's final save
    //    happen. A procedure stuck in a hung instrument call is aborted; any
    //    command still in flight goes through the same instrument lock as the
    //    cleanup's, so the cleanup's still come after.
    match tokio::time::timeout(SHUTDOWN_TIMEOUT, &mut procedure_task).await {
        Ok(_) => info!("The procedure has stopped"),
        Err(_) => {
            error!(
                "the procedure didn't stop within {:?}, aborting it",
                SHUTDOWN_TIMEOUT
            );
            procedure_task.abort();
        }
    }

    // 3. Put the filament system into a safe state. A hung instrument mustn't
    //    stop the terminal being restored, so this is bounded too.
    let cleanup =
        match tokio::time::timeout(CLEANUP_TIMEOUT, hardware.filament.enter_safe_state()).await {
            Ok(Ok(())) => {
                info!("Put the filament system into a safe state");
                Ok(())
            }
            Ok(Err(e)) => Err(e.to_string()),
            Err(_) => {
                error!(
                    "putting the filament system into a safe state didn't finish within {:?}",
                    CLEANUP_TIMEOUT
                );
                Err(format!(
                    "cleanup didn't finish within {:?}",
                    CLEANUP_TIMEOUT
                ))
            }
        };

    // Read the TMP's state fresh rather than trusting the last snapshot, which
    // is stale if it's the vacuum side that failed. `None` if it can't be read.
    let tmp_running = match tokio::time::timeout(CLEANUP_TIMEOUT, hardware.vacuum.snapshot()).await
    {
        Ok(Ok(snapshot)) => Some(snapshot.tmp_running),
        Ok(Err(e)) => {
            error!("couldn't read the TMP's state: {}", e);
            None
        }
        Err(_) => {
            error!(
                "reading the TMP's state didn't finish within {:?}",
                CLEANUP_TIMEOUT
            );
            None
        }
    };

    // 4. After a failure, and only once the filament is safe, show what went
    //    wrong until the operator presses a key.
    if let Ok(Shutdown::Error(_)) = &result {
        let acknowledged = async {
            app.show_cleanup(&cleanup)?;
            app.acknowledge(&mut terminal).await
        }
        .await;
        if let Err(e) = acknowledged {
            error!("couldn't show the error: {}", e);
        }
    }

    // 5. Restore the terminal and report.
    //
    // The terminal may be gone by now — that's what SIGHUP means — so nothing
    // from here may panic on a failed write. `ratatui::restore` would report
    // its own failure with `eprintln!`, which panics when stderr is closed.
    if let Err(e) = ratatui::try_restore() {
        error!("couldn't restore the terminal: {}", e);
    }
    info!("Exiting");

    // The results are only written once the procedure has started, so there
    // may be nothing to point at.
    if results_path.exists() {
        report(format_args!(
            "Results written to {}",
            results_path.display()
        ));
    }
    if let Err(e) = &cleanup {
        report_error(format_args!(
            "Warning: the filament system may still be powered: {}",
            e
        ));
    }

    // After a completed run the procedure has already stopped the TMP.
    match tmp_running {
        Some(false) => {}
        Some(true) => report(format_args!(
            "The TMP is still running. Use the vacuum control binary to stop it."
        )),
        None => report(format_args!(
            "Couldn't read the TMP's state, so it may still be running. Check it, and use the \
             vacuum control binary to stop it."
        )),
    }

    match result? {
        Shutdown::Normal => Ok(()),
        Shutdown::Error(message) | Shutdown::Panicked(message) => Err(message.into()),
    }
}

/// Builds the hardware the application talks to.
///
/// `--mock` mocks both subsystems. The two are separate `Arc`s so that one can
/// be mocked without the other, which is a change here rather than a new flag.
async fn build_hardware(args: &Arguments) -> Result<Hardware, HardwareError> {
    if args.mock {
        info!("Running against mocked hardware");
        return Ok(Hardware {
            filament: Arc::new(MockFilamentSystem::default()),
            vacuum: Arc::new(MockVacuumSystem::default()),
        });
    }

    info!("Running against real hardware");

    // Present because clap's `required_unless_present = "mock"` on each makes
    // them so, and this branch is only reached without `--mock`.
    let device_path = args.device_path.as_deref().expect("missing device path");
    let adc_gauge_number = args.adc_gauge_number.expect("missing ADC gauge number");
    let tmp_address = args.tmp_address.as_deref().expect("missing TMP address");

    // One controller, shared by the ADC, the TMP and the polarity relays.
    let controller = Arc::new(Controller::new(device_path).map_err(|source| {
        error!(
            "failed to open the controller at {}: {}",
            device_path, source
        );
        HardwareError::Controller {
            path: device_path.to_string(),
            source,
        }
    })?);

    Ok(Hardware {
        filament: Arc::new(RealFilamentSystem::new(Arc::clone(&controller)).await?),
        vacuum: Arc::new(RealVacuumSystem::new(controller, adc_gauge_number, tmp_address).await?),
    })
}

/// Initialise `env_logger` to log to `out/app.log`.
fn init_logging() -> Result<(), std::io::Error> {
    fs::create_dir_all("out")?;
    let file = fs::OpenOptions::new()
        .append(true)
        .create(true)
        .open("out/app.log")?;

    Builder::from_default_env()
        .target(Target::Pipe(Box::new(file)))
        .init();

    info!("Application started");
    Ok(())
}

#[derive(Parser)]
struct Arguments {
    /// The path to the controller device, e.g. /dev/tty.usbmodem11201.
    #[arg(required_unless_present = "mock")]
    device_path: Option<String>,

    /// The gauge number to use when communicating with the ADC, e.g. 1.
    #[arg(
        required_unless_present = "mock",
        value_parser = clap::value_parser!(u8).range(1..=2)
    )]
    adc_gauge_number: Option<u8>,

    /// The address of the TMP in the RS-485 Pfeiffer Vacuum Protocol, e.g. 001.
    ///
    /// This corresponds to TMP parameter 797.
    #[arg(required_unless_present = "mock")]
    tmp_address: Option<String>,

    /// Run against simulated hardware instead of the real rig.
    #[arg(long)]
    mock: bool,

    /// Run without pumping down the chamber, e.g. to test against a precision
    /// resistor on the bench.
    ///
    /// The vacuum hardware must still be connected, but the TMP is never
    /// started, and the chamber's pressure and the TMP aren't checked while
    /// current flows.
    #[arg(long)]
    no_vacuum: bool,
}

/// The message a panic was raised with, if it was a string.
fn panic_message(panic: &(dyn Any + Send)) -> String {
    panic
        .downcast_ref::<&str>()
        .map(|message| message.to_string())
        .or_else(|| panic.downcast_ref::<String>().cloned())
        .unwrap_or_else(|| String::from("no message"))
}

/// Prints a line for the operator once the terminal has been restored.
///
/// Unlike `println!` it doesn't panic if the write fails, which it does when
/// the terminal has been closed. There's nobody to tell by then anyway.
fn report(line: std::fmt::Arguments) {
    let _ = writeln!(std::io::stdout(), "{}", line);
}

/// As `report`, but for errors and warnings, on stderr.
fn report_error(line: std::fmt::Arguments) {
    let _ = writeln!(std::io::stderr(), "{}", line);
}

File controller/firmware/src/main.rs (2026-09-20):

#![no_main]
#![no_std]

use common::{ControllerError, USB_MAX_PACKET_SIZE};
use core::fmt::Write;
use defmt::*;
use embassy_executor::Spawner;
use embassy_rp::{
    Peri, binary_info, bind_interrupts, dma,
    gpio::{Level, Output},
    interrupt::typelevel::Binding,
    pac,
    peripherals::{UART0, UART1, USB},
    uart::{self, Uart},
    usb,
};
use embassy_time::{Duration, Timer, with_timeout};
use embassy_usb::{
    UsbDevice,
    class::cdc_acm::{BufferedReceiver, CdcAcmClass, Sender, State},
    driver::EndpointError,
};
use embedded_io_async::Read;
use static_cell::StaticCell;
use string_buffer::StringBuffer;
use {defmt_rtt as _, panic_probe as _};

bind_interrupts!(struct Irqs {
    UART0_IRQ => uart::InterruptHandler<UART0>;
    UART1_IRQ => uart::InterruptHandler<UART1>;
    USBCTRL_IRQ => usb::InterruptHandler<USB>;
});

mod string_buffer;

// This data appears in the output of `pictool info`[1].
//
// 1: https://docs.rs/rp-binary-info/0.1.1/rp_binary_info/
#[unsafe(link_section = ".bi_entries")]
#[used]
pub static PICOTOOL_ENTRIES: [binary_info::EntryAddr; 3] = [
    binary_info::rp_program_name!(c"SEM controller"),
    binary_info::rp_program_description!(c"Controls my DIY SEM"),
    binary_info::rp_cargo_version!(),
];

#[embassy_executor::main]
async fn main(spawner: Spawner) {
    let peripherals = embassy_rp::init(Default::default());

    // Initialise the USB device and the CDC ACM sender/receiver.
    let (usb_device, mut sender, mut receiver) = init_usb(peripherals.USB);

    // Spawn a task to run the USB driver.
    spawner.spawn(usb_task(usb_device).unwrap());

    // Initialise the UART driver for the Edwards ADC MkII (pressure gauge).
    //
    // This is connected to an RS-232 converter, so we can read/write as usual.
    let mut uart0 = init_uart(
        peripherals.UART0,
        peripherals.PIN_16,
        peripherals.PIN_17,
        Irqs,
        peripherals.DMA_CH0,
        peripherals.DMA_CH1,
    );

    // Initialise the UART driver for the Pfeiffer TC 600 (TMP controller).
    //
    // This is connected to an RS-485 converter, so we can read/write as usual.
    let mut uart1 = init_uart(
        peripherals.UART1,
        peripherals.PIN_4,
        peripherals.PIN_5,
        Irqs,
        peripherals.DMA_CH2,
        peripherals.DMA_CH3,
    );

    // The RS-485 converter contains a driver and a receiver, both connected to
    // the same bus. To receive we want the driver disabled and the receiver
    // enabled (otherwise the driver would drive the line high while idle). To
    // transmit we want the opposite (otherwise we would receive our own
    // transmission). Set this pin high to transmit and set it low to read.
    let mut uart1_transmit_pin = Output::new(peripherals.PIN_3, Level::Low);

    // The two relays on the controller. When a pin is low the relay is in its
    // base state (nc is connected), when it's high it's in its active state (no
    // is connected). They hold their state until the next RLY command.
    let mut relay_1_pin = Output::new(peripherals.PIN_18, Level::Low);
    let mut relay_2_pin = Output::new(peripherals.PIN_19, Level::Low);

    // USB packets that are exactly the maximum packet size aren't processed
    // until a subsequent shorter packet is sent. We may not have a subsequent
    // packet to send but we want all packets to be sent immediately. Set the
    // buffer size to be 1 byte smaller than the maximum to avoid this problem.
    let mut command = [0u8; USB_MAX_PACKET_SIZE as usize - 1];
    let mut response = [0u8; USB_MAX_PACKET_SIZE as usize - 1];

    loop {
        // Wait for a USB host to connect.
        info!("Waiting for USB host");
        receiver.wait_connection().await;
        info!("USB host connected");

        loop {
            let result: Result<(), ControllerError> = (async {
                // Read a command from the USB host.
                let command_length = read_command(&mut receiver, &mut command).await?;

                // Change the last character of the command to a carriage
                // return, as is expected by both the ADC and the TMP.
                command[command_length - 1] = b'\r';

                // Split the command into destination and command.
                let destination = &command[..3];
                let command = &command[4..command_length];

                let mut response_length: usize;
                match destination {
                    b"ADC" => {
                        write_command(command, "ADC", &mut uart0).await?;
                        response_length = read_response(&mut response, "ADC", &mut uart0).await?;
                    }
                    b"RLY" => {
                        response_length = match command {
                            b"?\r" => get_relays(&relay_1_pin, &relay_2_pin, &mut response),
                            _ => set_relays(
                                command,
                                &mut relay_1_pin,
                                &mut relay_2_pin,
                                &mut response,
                            )?,
                        };
                    }
                    b"TMP" => {
                        write_rs_485_command(
                            command,
                            "TMP",
                            &mut uart1_transmit_pin,
                            &mut uart1,
                            &pac::UART1,
                        )
                        .await?;
                        response_length = read_response(&mut response, "TMP", &mut uart1).await?;
                    }
                    _ => return Err(ControllerError::UnknownDestination),
                }

                // Our response to the USB host must be terminated by a
                // carriage return followed by a newline (\r\n). Both the ADC
                // and the TMP terminate their responses with a carriage return
                // (\r) so we just need to add a newline. Ensure there's enough
                // space in the buffer to do that, then do it.
                if response_length == response.len() {
                    return Err(ControllerError::ResponseTooLong);
                }
                response[response_length] = b'\n';
                response_length += 1;

                // Send the response to the USB host.
                send_response(&response[..response_length], &mut sender).await
            })
            .await;
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

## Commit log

2025-11-28 Support controlling the Edwards ADC MkII
2025-12-02 Set up the Raspberry Pi Debug Probe and defmt logging
2026-01-06 Proxy messages from the USB host to the ADC and TMP
2026-01-08 Set up workspace, move error type to a common crate
    [main.rs]
2026-01-09 Format error responses using Display and Write
    [main.rs]
2026-01-12 Add Adc struct
2026-01-20 Graph and log pressure over time
2026-01-21 Force graph to refresh in VS code, graph time in minutes, prevent invalid files on termination
    [main.rs]
2026-01-25 Add controller PCB design
    [controller.kicad_pcb, controller.kicad_sch]
2026-01-27 Restructure the repository, update the README
    [controller.kicad_pcb, controller.kicad_sch]
2026-01-27 Set up build123d for the controller case
    [case.stl]
2026-02-03 Revert "Set up build123d for the controller case"
    This reverts commit 3bbeb0c9e4b1fe31b4117f66bcf109ab93aa7ac6.
    [case.stl]
2026-02-03 Add 3D models of the controller case
    [Body.stl, Case.f3d, Case.step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]
2026-02-03 Tweak case to reduce printing time
    [Body.stl, Case.f3d, Case.step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]
2026-02-06 Make micro USB B port hole bigger
    [Body.stl, Case.f3d, Case.step]
2026-04-27 Add the visualisation canvas and render a test electrode
2026-04-29 Draw a voltage legend
2026-05-11 Render voltage legend outside solution canvas
2026-05-26 Allow toggling the Wehnelt cylinder and anode
2026-05-26 Change electrode test to intersection rather than containment to support smaller filament sizes
2026-06-10 Add a Python script to connect to my oscilloscope via USB and print its ID
2026-06-10 Update the Python script to read the average voltage of channel 1 on the scope
2026-06-13 Add a script to connect to and control my power supply
2026-09-02 Ignore KiCad history folder
2026-09-02 Teach controller about relays
2026-09-17 Update controller case and repository structure
    [Body.stl, Case.f3d, Case.step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]
2026-09-18 Add filament mount 3D model
    [Mount.f3d, Mount.step]
2026-09-18 Rename directory
    [Mount.f3d, Mount.step]
2026-09-20 Add Oscilloscope and PowerSupply types
2026-09-22 Implement PowerSupply type
2026-09-25 Add PowerSupply::reset
2026-09-29 Add cold resistance calculation document
2026-09-29 Update cold resistance calculation document to reflect power supply tests
2026-09-30 Add OCP and regulation mode methods to PowerSupply
2026-09-30 Read voltages from a single acquisition
2026-09-30 Add FilamentSystem::set_vertical_scale
2026-09-30 Pin Python version
2026-10-01 Start implementing cold resistance measurement
2026-10-01 Perform cold resistance analysis
2026-10-01 Calculate current gain and offset bounds once
2026-10-01 Add --no-vacuum flag for testing with a precision resistor
2026-10-04 Render cold resistance points
2026-10-06 Fix dropped voltage readings
2026-10-07 Add bin to determine if the filament mount is heating/cooling over time
2026-10-08 Add temperature compensation design document
2026-10-08 Measure reference currents to track heating
2026-10-10 Correct temperature drift in cold resistance calculation
    [characterisation.rs]
2026-10-13 Change cold resistance section numbering
2026-10-14 Update filament-characterisation README
2026-10-26 Add mount warming analysis docs and script
2026-10-26 Add pulse heating design document
2026-10-26 Move shared filament characterisation code to a library
2026-10-26 Initial pulse heating implementation
2026-10-26 Implement polarity reversal for probe currents
2026-10-27 Allow clipped voltages while the filament is cooling after the pulse
